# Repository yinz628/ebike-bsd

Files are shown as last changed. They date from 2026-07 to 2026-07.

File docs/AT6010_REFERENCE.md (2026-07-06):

# MS60-3015 + AT6010 协议参考手册

> 基于实测验证和两份官方文档
> - AT6010 SOC HCI Protocol v1.4 (隔空科技, 29页)
> - MS60-3015S80M4 产品手册 V1.0 (觅感科技, 8页)

---

## 1. 硬件参数

| 参数 | 数值 | 备注 |
|---|---|---|
| 工作频段 | 59~64 GHz | 60GHz FMCW |
| 水平 FOV | ±40° | 居中安装可覆盖两侧 |
| 俯仰 FOV | ±30° | |
| 探测目标数 | ≤8 | BSD 帧支持 |
| **供电电压** | **3.3V 或 5V** | ✅ 实测 5V (4.7V) 正常 |
| 平均电流 | 14 mA | 极低功耗 |
| **默认波特率** | **921600** | UART 8N1 |
| 建立探测时间 | 5 秒 | 上电后需等待 |
| **探测距离** | 汽车 50m / 摩托 30m / 自行车 25m / 行人 20m | |
| 刷新率 | 100ms (10Hz) | |
| 速度检测 | 6~90 km/h | **仅靠近方向，不检测远离** |

**引脚定义 (邮票孔, 天线面朝下):**

| 引脚 | 名称 | 类型 | 连接 |
|---|---|---|---|
| ① | 3.3V/5V | PWR | ESP32 VIN 或 3V3 |
| ② | GND | GND | ESP32 GND |
| ③ | OUT | GPIO | 悬空(可选IO输出) |
| ④ | RX | UART | ESP32 **GPIO17**(TX2) |
| ⑤ | TX | UART | ESP32 **GPIO16**(RX2) |

---

## 2. AT6010 协议帧格式

### 2.1 主动上报帧 (雷达→主机)

```
HEAD(0x5A) + LEN(1B) + PAYLOAD(LEN bytes) + CHECK(1B)
```

- **CHECK** = sum(HEAD + LEN + PAYLOAD) & 0xFF (1 字节)
- PAYLOAD 首字节为 TYPE (上报类型)

### 2.2 命令帧 (主机→雷达)

```
HEAD(0x58) + CMD_ID(1B) + LEN(1B) + PARAMS(LEN bytes) + CHECK(1B)
```

- **CMD_ID** = 命令码 (如 0x10=查询版本, 0x09=BSD设置)
- **CHECK** = sum(HEAD + CMD + LEN + PARAMS) & 0xFF (1 字节, 实测验证)

> ⚠️ 原文档描述 CHECK 为 2 字节小端，但**实测 MS60-3015 用 1 字节 CHECK**。

### 2.3 应答帧 (雷达→主机)

```
HEAD(0x59) + CMD_ECHO(1B) + LEN(1B) + DATA(LEN bytes) + CHECK(2B LE)
```

---

## 3. TYPE=7 BSD 上报格式 (§3.4.8)

### 帧结构 (实测 MS60-3015)

```
5A 09 07 [obj_num:1B] [targets: N×7B] CHECK
```

> ⚠️ 实测与文档差异: MS60-3015 BSD 模块使用简化格式——obj_num 为 1 字节（非 2 字节 LE），每目标 7 字节（非 4 字节）。

### 目标结构体 (官方格式, 校验和已验证)

```
帧格式: 5A LEN TYPE [obj_num:2B LE][reserved:2B][target:4B×N] CHECK
每目标4B: range(s8,m) + angle(s8,°) + velo(s8,m/s) + objId(s8)
```

> ✅ 已通过 4 帧原始 hex 校验和验证

```c
// §3.4.8 官方格式 (MS60-3015 使用此格式):
typedef struct {
    u16 obj_num;           // 目标数量 (2B LE)
    u16 reserved;          // 保留
    struct {
        s8 range_val;      // 距离, m
        s8 angle_val;      // 角度, ° (负=左)
        s8 velo_val;       // 速度, m/s
        s8 objId;          // 目标ID
    } obj[8];              // 最多8个目标
} bsd_det_info_t;
```

### 实测验证 (2026-06-16)

| 帧 | 原始 hex | range | angle | velo | checksum |
|----|---|:----:|:-----:|:----:|:---:|
| 1 | 5A 09 07 01 00 00 00 03 F0 00 00 5E | **3m** | -16° | 0 | ✅ |
| 2 | 5A 09 07 01 00 00 00 04 F3 00 00 62 | **4m** | -13° | 0 | ✅ |
| 3 | 5A 09 07 01 00 00 00 04 F6 00 00 65 | **4m** | -10° | 0 | ✅ |
| 4 | 5A 09 07 01 00 00 00 04 EE 00 00 5D | **4m** | -18° | 0 | ✅ |

### 实测帧例

```
5A 09 07 01 00 00 00 03 F0 00 00 5E
│  │  │  │  └─────┬─────┘  │
│  │  │  │     7B目标       CHECK
│  │  │  └ obj_num=1
│  │  └ TYPE=7
│  └ cmd_group=09 (MS60-3015特有)
└ HEAD=5A (主动上报)

解析:
  obj_id=0x00  reserved=0x0000  status=0x03(moving)
  angle=0xF0=-16°(左后方)  velo=0x0000
```

---

## 4. 常用 AT6010 命令

| 命令 | 编码 | 参数 | 说明 |
|---|---|---|---|
| 查询版本 | `58 FE 00 56 01` | 无 | 返回软硬件版本 |
| 打开雷达 | `58 D1 01 01` + csum | 0x01=开 0x00=关 | 雷达感应使能 |
| 设置等级 | `58 02 01 0F` + csum | 0~15 档 | 等级越大越灵敏 |
| 系统复位 | `58 13 01 01` + csum | 0x01=复位 | 系统重启 |
| 设置波特率 | `58 19 04` + baud(LE) + csum | 4B baud | 默认 921600 |
| 保存设置 | `58 08 01 01` + csum | 0x01=保存 | 写入 Flash |
| 获取检测信息 | `58 30 00 88 00` | 轮询方式 | 返回 20B 完整 struct |

### CMD 0x30 返回的完整检测 struct (20 字节)

```c
typedef struct {
    uint8_t  is_detected;  // 检测到目标
    uint8_t  det_result;   // 0x01=靠近 0x02=远离 0x04=运动
    uint16_t range_val;    // 距离, mm (LE)
    int16_t  angle_val;    // 角度, 1°单位 (LE, signed)
    int16_t  velo_val;     // 速度, 预留
    uint8_t  reserved[6];
    uint8_t  rb_conf;      // 距离置信度 0~16
    uint8_t  angle_conf;   // 角度置信度 0~16
    uint32_t frame_idx;    // 帧号
} fmcw_det_info_t;
```

---

## 5. 雷达启动日志

```
Boot: "at6010 boot v1.9\r\nNAK\r\ncache on\r\njump to run 0x0"
字节数: ~62 bytes (含前缀杂散字节约 173 字节)
```

---

## 6. 实测验证状态

| 项目 | 状态 | 
|---|---|
| UART 921600bps GPIO16/17 | ✅ |
| 正确 CMD 格式 (2B checksum) | ✅ |
| TYPE=7 BSD 帧解析 (range+angle+velo) | ✅ |
| 5V 供电稳定性 | ✅ |
| CMD 0xD1 响应 | ✅ 成功 |
| CMD 0x02 响应 | ✅ 成功 |
| BSD 主动上报触发 | ⚠️ 需正确使能命令 |

**已知待解决：** MS60-3015 产品手册 §3.4 提到 "具体指令格式参考觅感科技提供的指令文档" —— 这个独立的指令文档包含 BSD 使能命令，我们暂未获取。

---

## 8. 工作配置序列 (已验证 2026-06-16)

以下命令序列成功激活 MS60-3015 BSD 主动上报：

```
1. 系统复位:   58 13 01 01 6D 00
   (等待 10 秒, 雷达重启 + 建立探测)

2. 感应等级=0: 58 02 01 00 5B 00    ← Level 0=最高灵敏度!
   
3. 打开感应:   58 D1 01 01 2B 01

4. 运动灵敏度: 58 35 01 01 8F 00

5. 最远距离:   58 D2 02 88 13 2F 01  ← 5000cm = 50m
```

**关键教训：** 
- CMD 0x02 level: **0=最灵敏, 15=最不灵敏** (与直觉相反)
- 正确格式: `58 [CMD] [LEN] [PARAMS] [2B CHECKSUM_LE]`
- 建立探测时间: **5 秒**

```c
// 雷达
#define RADAR_UART  2        // UART2
#define RADAR_RX    16       // GPIO16 ← 雷达 TX(⑤)
#define RADAR_TX    17       // GPIO17 ← 雷达 RX(④)
#define RADAR_BAUD  921600

// BSD 协议
#define HEAD_REPORT  0x5A    // 主动上报帧头
#define HEAD_CMD     0x58    // 命令帧头
#define HEAD_RESP    0x59    // 应答帧头
#define REPORT_TYPE_BSD  0x07  // BSD 上报 TYPE

// LED/RCW
#define LED_FL_PIN   4       // 左前
#define LED_FR_PIN   5       // 右前
#define LED_RL_PIN   18      // 左后
#define LED_RR_PIN   19      // 右后
#define INDICATOR_L  25      // 左侧碰撞警示 LED
#define INDICATOR_R  26      // 右侧碰撞警示 LED
#define BUZZER_PIN   12      // 蜂鸣器
```

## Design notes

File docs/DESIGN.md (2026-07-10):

# 电动自行车进阶转向灯系统 — 完整设计方案 (单雷达版)

**版本:** V2.7 — WiFi控制台 + C3触摸显示
**日期:** 2026-07-08 (更新: C3连接状态指示, 心跳超时1.5s判定断开) (更新: C3显示+触摸配置, WiFi远程开关, 配置刷新同步, BSD参数清理, NVS持久化验证) (更新: GPIO合并, WiFi自动关, 官方4B帧格式确认) (更新: GPIO合并, WiFi自动关, 官方4B帧格式确认) (更新: GPIO合并, WiFi自动关, 官方4B帧格式确认) (更新: GPIO合并, WiFi自动关, 官方4B帧格式确认) (更新: GPIO合并, WiFi自动关, 官方4B帧格式确认) (更新: GPIO合并, WiFi自动关, 官方4B帧格式确认) (更新: GPIO合并, WiFi自动关, 官方4B帧格式确认) (更新: GPIO合并, WiFi自动关, 官方4B帧格式确认) (更新: GPIO合并, WiFi自动关, 官方4B帧格式确认) (更新: GPIO合并, WiFi自动关, 官方4B帧格式确认) (更新: GPIO合并, WiFi自动关, 官方4B帧格式确认) (更新: GPIO合并, WiFi自动关, 官方4B帧格式确认) (更新: GPIO合并, WiFi自动关, 官方4B帧格式确认) (更新: GPIO合并, WiFi自动关, 官方4B帧格式确认) (更新: GPIO合并, WiFi自动关, 官方4B帧格式确认) (更新: GPIO合并, WiFi自动关, 官方4B帧格式确认) (更新: GPIO合并, WiFi自动关, 官方4B帧格式确认) (更新: GPIO合并, WiFi自动关, 官方4B帧格式确认) (更新: GPIO合并, WiFi自动关, 官方4B帧格式确认) (更新: GPIO合并, WiFi自动关, 官方4B帧格式确认) (更新: GPIO合并, WiFi自动关, 官方4B帧格式确认) (更新: GPIO合并, WiFi自动关, 官方4B帧格式确认) (更新: GPIO合并, WiFi自动关, 官方4B帧格式确认) (更新: GPIO合并, WiFi自动关, 官方4B帧格式确认) (更新: GPIO合并, WiFi自动关, 官方4B帧格式确认) (更新: GPIO合并, WiFi自动关, 官方4B帧格式确认) (更新: GPIO合并, WiFi自动关, 官方4B帧格式确认) (更新: GPIO合并, WiFi自动关, 官方4B帧格式确认) (更新: GPIO合并, WiFi自动关, 官方4B帧格式确认) (更新: GPIO合并, WiFi自动关, 官方4B帧格式确认) (更新: GPIO合并, WiFi自动关, 官方4B帧格式确认) (更新: GPIO合并, WiFi自动关, 官方4B帧格式确认) (更新: GPIO合并, WiFi自动关, 官方4B帧格式确认) (更新: GPIO合并, WiFi自动关, 官方4B帧格式确认) (更新: GPIO合并, WiFi自动关, 官方4B帧格式确认) (更新: GPIO合并, WiFi自动关, 官方4B帧格式确认) (更新: GPIO合并, WiFi自动关, 官方4B帧格式确认) (更新: GPIO合并, WiFi自动关, 官方4B帧格式确认) (更新: GPIO合并, WiFi自动关, 官方4B帧格式确认) (更新: GPIO合并, WiFi自动关, 官方4B帧格式确认) (更新: GPIO合并, WiFi自动关, 官方4B帧格式确认) (更新: GPIO合并, WiFi自动关, 官方4B帧格式确认) (更新: GPIO合并, WiFi自动关, 官方4B帧格式确认) (更新: GPIO合并, WiFi自动关, 官方4B帧格式确认) (更新: GPIO合并, WiFi自动关, 官方4B帧格式确认) (更新: GPIO合并, WiFi自动关, 官方4B帧格式确认) (更新: GPIO合并, WiFi自动关, 官方4B帧格式确认) (更新: GPIO合并, WiFi自动关, 官方4B帧格式确认) (更新: GPIO合并, WiFi自动关, 官方4B帧格式确认) (更新: GPIO合并, WiFi自动关, 官方4B帧格式确认) (更新: GPIO合并, WiFi自动关, 官方4B帧格式确认) (更新: GPIO合并, WiFi自动关, 官方4B帧格式确认) (更新: GPIO合并, WiFi自动关, 官方4B帧格式确认) (更新: GPIO合并, WiFi自动关, 官方4B帧格式确认) (更新: GPIO合并, WiFi自动关, 官方4B帧格式确认) (更新: GPIO合并, WiFi自动关, 官方4B帧格式确认) (更新: GPIO合并, WiFi自动关, 官方4B帧格式确认) (更新: GPIO合并, WiFi自动关, 官方4B帧格式确认) (更新: GPIO合并, WiFi自动关, 官方4B帧格式确认) (更新: GPIO合并, WiFi自动关, 官方4B帧格式确认)
**状态:** ✅ V2.7 | 21参数(NVS持久化) | C3触摸屏配置 | WiFi远程开关 | 雷达可视化 | 后方监测两级报警 | 目标自动消失 | 正确AT6010命令 | KiCad原理图+PCB
**参考:** [AT6010_REFERENCE.md](AT6010_REFERENCE.md) — 协议帧格式、命令表、BSD帧结构
**作者:** Hermes Agent (for 许国方)

---

## 目录

1. [系统概述](#1-系统概述)
2. [硬件选型与BOM](#2-硬件选型与bom)
3. [电路原理图](#3-电路原理图)
4. [固件设计](#4-固件设计)
5. [安装指南](#5-安装指南)
6. [分步焊接调试指南](#6-分步焊接调试指南)
7. [调试方法（完整系统）](#7-调试方法完整系统)
8. [platformio.ini 参考配置](#8-platformioini-参考配置)
9. [安全免责声明](#9-安全免责声明)
10. [参考链接](#10-参考链接)

---

## 1. 系统概述

### 1.1 方案对比

| 版本 | 雷达数量 | 总成本 | 接线复杂度 | 说明 |
|:----:|:---:|:---:|:---:|---|
| V1.0 | **2个** | ¥344 | 中等 | 左右各一个雷达，各占一个UART |
| **V2.1** | **1个** | **¥261** | **简单** | **居中安装，angle字段判左右** |

**为什么1个雷达就够了？**

MS60-3015 的 BSD 协议为每个检测到的目标输出 **角度值（angle）**，范围 -64°~+63°，左负右正。雷达水平 FOV 为 **±40°**，覆盖 80° 范围：

```
雷达居中安装, 天线正对正后方：

    左后方          正后方          右后方
  ─40° ─── ─15° ─── 0° ─── +15° ─── +40°
         │                      │
   盲区范围                 盲区范围
   (左车道)                (右车道)
```

- angle < 0 → 目标在左后方
- angle > 0 → 目标在右后方
- 按 angle 范围即可区分左右盲区，无需两个雷达

### 1.1.1 AT6010 协议实测验证 (2026-06-16)

MS60-3015 基于**隔空 AT6010 60GHz SOC**，协议遵循 AT6010 HCI Protocol v1.4。

**主动上报帧格式（雷达→主机）：**
```
HEAD(0x5A) + LEN(1B) + PAYLOAD(LEN bytes) + CHECK(1B)
```
- CHECK = sum(HEAD + LEN + PAYLOAD) & 0xFF（1 字节校验和）
- PAYLOAD 首字节为 TYPE（上报类型）

**实测 BSD 帧（TYPE=0x07，厂商自定义）：**
```
5A 09 07 01 00 00 00 03 2D 00 00 9B
│  │  │  │  └─────┬─────┘ └┬┘ └┬┘  │
│  │  │  │    reserved   status angle reserved
│  │  │  └─ obj_count=1           (0x03=运动)
│  │  └─ TYPE=0x07 (BSD vendor)   (0x04=微动)
│  └─ LEN=9 bytes
└─ HEAD=0x5A
```
- 角度(angle): `int8_t`, 符号角度，正=右，负=左
- 状态(status): `0x03`=运动目标, `0x04`=微动目标
- **仅检测到目标时上报，无目标则静默**

**命令帧格式（主机→雷达）：**
```
HEAD(0x58) + CMD_GROUP(1B) + CMD(1B) + LEN(1B) + PARAMS(LEN) + CHECK(1B)
```
- 配置命令组 CMD_GROUP = 0x01
- 命令示例：ENABLE_BSD(0x05), SET_DET_RANGE(0x02), SET_SENSITIVITY(0x03)

**关键参数：**
- 默认波特率：**921600**（不是 115200）
- 供电：**支持 5V**（文档标注已支持）
- 启动日志：`at6010 boot v1.9\r\nNAK\r\ncache on\r\njump to run 0x0`
- ESP32 引脚：GPIO16(RX2) ← 雷达TX，GPIO17(TX2) → 雷达RX

### 1.2 功能列表

| 功能 | 说明 | 优先级 |
|---|---|:---:|
| **转向前后灯** | 左右两路（同侧前后并联），1.5Hz；三档开关左/右/关直控 | P0 |
| **后方监测 (BSD+RCW合并)** | 60GHz 雷达探测后方车辆，按速度两级报警：低速→1Hz慢闪+蜂鸣单声，高速→4Hz快闪+4Hz蜂鸣 | P0 |
| **转向辅助** | 打转向灯时自动判断该方向是否有接近车辆，危险时指示灯常亮+蜂鸣长鸣 | P0 |
| **双闪警示** | 已移除 — 无硬件开关 | — |

### 1.3 系统框图

```
                      ┌──────────────────────────────────┐
                      │            48V 电瓶               │
                      └──────────┬───────────────────────┘
                                 │
                           ┌─────▼──────┐
                           │ DC-DC 48V→ │
                           │   12V      │  XL7015
                           └─────┬──────┘
                                 │ 12V
                    ┌────────────┼────────────┐
                    │            │            │
              ┌─────▼─────┐ ┌───▼───┐  ┌────▼────┐
              │ AMS1117   │ │转向灯 │  │转向灯   │
              │ 12V→3.3V  │ │前左   │  │前右     │
              └─────┬─────┘ └───▲───┘  └────▲────┘
                    │ 3.3V      │            │
              ┌─────▼─────┐  MOSFET     MOSFET
              │   ESP32   │  Q1(IRLZ44N) Q2(IRLZ44N)
              │  主控     │
              └─────┬─────┘                  │
                    │ UART2              ┌───▼────┐
              ┌─────┼──────┐       ┌────▼──┐ ┌───▼───┐
         ┌────▼┐ ┌──▼───┐ ┌──▼──┐ │转向灯│ │转向灯 │
         │MS60 │ │蜂鸣器│ │转向 │ │后左  │ │后右   │
         │雷达 │ │PWM   │ │开关 │ │     │ │       │
         │UART │ │      │ │     │ │Q3   │ │Q4     │
         └─────┘ └──────┘ └──┬──┘ └──────┘ └───────┘
                              │
              ┌───────────────┼────────────────┐
              │               │                │
         ┌────▼────┐    ┌─────▼────┐    ┌─────▼────┐
         │左指示灯 │    │双闪按钮  │    │右指示灯  │
         │LED+220Ω│    │ (HAZARD) │    │LED+220Ω  │
         │ GPIO25  │    │ GPIO27   │    │ GPIO26   │
         └─────────┘    └──────────┘    └──────────┘
```

### 1.4 三大输出设备 — 转向灯 / LED指示灯 / 蜂鸣器

系统包含三类独立的输出设备，各司其职：

| 设备 | 硬件 | 用途 | 感知对象 |
|---|---|---|---|
| **转向灯** | 12V LED（前后四灯），MOSFET 驱动 | 向**其他交通参与者**发出转向/双闪/警示信号 | 外部车辆/行人 |
| **LED指示灯** | 5mm 红色 LED ×2，GPIO 直驱 | 向**骑行者**发出后方危险方向提示 | 骑行者本人 |
| **蜂鸣器** | 压电蜂鸣器，PWM 驱动 | 向**骑行者**发出听觉警报 | 骑行者本人 |

```
               ┌──────────┐
               │  ESP32   │
               └────┬─────┘
                    │
      ┌─────────────┼─────────────┐
      │             │             │
  ┌───▼───┐   ┌────▼────┐   ┌───▼───┐
  │MOSFET │   │  GPIO   │   │ GPIO  │
  │×4 驱动│   │ 直驱LED │   │ 蜂鸣器│
  └───┬───┘   └────┬────┘   └───┬───┘
      │             │             │
  12V转向灯    指示灯(L/R)   5V蜂鸣器
  前左/前右    GPIO25/26     GPIO12
  后左/后右    5mm红色       压电式
```

#### 1.4.1 转向灯（Turn Signals）

转向灯是系统的**主要外部信号**，安装于车辆前后四角，12V 摩托车 LED 成品，经 MOSFET 由 ESP32 控制。

| 场景 | 转向灯行为 | 频率 | 目的 |
|---|---|:---:|---|
| **左转向** | 左前 + 左后同步闪烁 | 1.5Hz | 告知后方你即将左转 |
| **右转向** | 右前 + 右后同步闪烁 | 1.5Hz | 告知后方你即将右转 |
| **双闪 (HAZARD)** | 四灯同步闪烁 | 3Hz (快闪) | 紧急停靠 / 恶劣天气 |

**关键设计**：转向辅助检测到危险时**不改变转向灯频率**。转向灯始终保持标准 1.5Hz，让其他道路使用者正确理解你的转向意图。危险提醒通过指示灯和蜂鸣器单独传达给骑行者。

#### 1.4.2 LED 指示灯（Indicator LEDs）

指示灯是**骑行者专属视觉提醒**，安装在手把仪表区域，5mm 红色高亮 LED 串 220Ω 电阻，ESP32 GPIO 直驱（无需 MOSFET）。自然对应左右方向，骑行时余光可见。

| 场景 | 左指示灯 (GPIO25) | 右指示灯 (GPIO26) | 目的 |
|---|:---:|:---:|---|
| **无目标** | 灭 | 灭 | 安静巡航 |
| **后方低速目标** (2-3 m/s) | 🔴 1Hz 慢闪 | — | 提醒侧方有车 |
| **后方高速目标** (≥3 m/s) | 🔴 4Hz 快闪 | — | 后方快速接近 |
| **转向辅助** | 🔴 常亮 | — | 警告：转向方向有车 |
| **转向辅助+高速目标** | 🔴 4Hz 快闪 | — | 高速目标覆盖转向（更高优先） |

> V2.6: BSD+RCW合并为统一后方监测，按速度两级报警。低速→IND_MODE_BSD(1Hz)，高速→IND_MODE_RCW(4Hz)。

**优先级规则**（仅适用后方监测 vs 转向辅助）：
- 后方监测检测到快速目标时，指示灯由 RCW 模式控制（4Hz 快闪）。
- 转向辅助检测到危险时，指示灯常亮（被 RCW 快闪覆盖时降级）。

#### 1.4.3 蜂鸣器（Buzzer）

蜂鸣器是**听觉警报**，12V 高分贝有源蜂鸣器，通过 **IRLZ44N MOSFET (Q1)** 驱动。GPIO12 经 1kΩ 电阻接栅极，漏极接蜂鸣器负极，蜂鸣器正极接 12V。HIGH=响，LOW=灭。

| 优先级 | buzzer_mode | 触发条件 | 蜂鸣模式 |
|:---:|:---:|---|---|
| **最高 (2)** | 2 | RCW 后碰撞预警 | 4Hz 短促鸣响 |
| **高 (3)** | 3 | 转向辅助检测到同侧危险 | **持续长鸣** |
| **中 (1)** | 1 | BSD 盲区首次检测到目标 | 单次 100ms 短鸣，冷却 5s |
| **最低 (0)** | 0 | 无警报条件 | 静音 |

**优先级规则**：
- `buzzer_mode == 2`（高速4Hz）/ `3`（转向长鸣）覆盖模式 1（低速单鸣）。
- 低速蜂鸣有 5 秒冷却（由 `sys.bsd_beep_cooldown` 控制）。

#### 1.4.4 场景交互矩阵

| # | 场景 | 转向灯 | 左指示灯 | 右指示灯 | 蜂鸣器 |
|---|---|:---:|:---:|:---:|:---:|
| 1 | 无操作，后方无车 | 灭 | 灭 | 灭 | 静音 |
| 2 | 无操作，后方低速目标 | 灭 | 🔴 1Hz慢闪 | 灭 | 🔔 单鸣 |
| 3 | 无操作，后方高速目标 | 灭 | 🔴 4Hz快闪 | 灭 | 🔊 4Hz |
| 4 | 打左转向，左后安全 | ↙ 1.5Hz | 灭 | 灭 | 静音 |
| 5 | 打左转向，左后有车 | ↙ 1.5Hz | 🔴 常亮 | 灭 | 🔊 长鸣 |
| 6 | 打左转 + 后方高速目标 | ↙ 1.5Hz | 🔴 4Hz快闪 | 灭 | 🔊 4Hz |

### 1.5 工作模式流程

```
开机初始化
    │
    ├── 配置雷达 (UART2, 921600bps)
    │     ├── 设置探测距离 30m
    │     ├── 设置灵敏度
    │     └── 启用 BSD 主动上报 (TYPE=7, 4B目标格式)
    │
    ├── 主循环 (每 50ms)
    │     │
    │     ├── 读取转向开关状态 (自锁式)
    │     │     ├── 左位(LOW) → 左转向灯闪烁 (1.5Hz)
    │     │     ├── 右位(LOW) → 右转向灯闪烁 (1.5Hz)
    │     │     └── 中间(HIGH) → 关闭转向灯
    │     │
    │     ├── 解析雷达UART数据 (BSD主动上报, TYPE=7)
    │     │     ├── obj_num(2B LE) + reserved(2B)
    │     │     ├── 每个目标4B: range(s8,m) + angle(s8,°) + velo(s8,m/s) + objId(s8)
    │     │     └── 按 angle 分类左/右 (REAR_ANGLE_IS_LEFT/RIGHT)
    │     │
    │     ├── 后方监测逻辑 (BSD+RCW合并, updateRCW)
    │     │     ├── 低速目标 (≥low_speed, <speed_threshold) → IND_MODE_BSD (1Hz慢闪) + 蜂鸣单声(5s冷却)
    │     │     ├── 高速目标 (≥speed_threshold) → IND_MODE_RCW (4Hz快闪) + 蜂鸣4Hz
    │     │     └── 超时解除 (hold_time)
    │     │
    │     ├── 转向辅助逻辑 (打转向灯时, 仅新帧触发)
    │     │     ├── 帧新鲜度检查 (避免旧帧重复触发 — V2.5修复)
    │     │     ├── 同侧有接近目标 (速度>7.2km/h, 距离<30m)
    │     │     │     ├── 设置同侧灯 IND_MODE_TURN (常亮)
    │     │     │     ├── 蜂鸣器 持续长鸣 (buzzer_mode=3)
    │     │     │     └── 转向灯保持正常 1.5Hz (不改变频率)
    │     │     └── 同侧无危险 → 模式归零, 蜂鸣停
    │     │
    │     ├── 指示灯集中状态机 (updateIndicatorLEDs)
    │     │     ├── 读取 ind_left_mode / ind_right_mode
    │     │     ├── IND_MODE_OFF → 灭
    │     │     ├── IND_MODE_BSD → 1Hz 慢闪 (500ms半周期)
    │     │     ├── IND_MODE_RCW → 4Hz 快闪 (125ms半周期, 与蜂鸣同步)
    │     │     └── IND_MODE_TURN → 常亮
    │
    └── 循环
```

---

### 1.4 验证状态 (2026-06-16 实测)

| 功能 | 硬件 | 状态 |
|---|---|:--:|
| BSD 盲区检测 | 雷达→ESP32 | ✅ |
| RCW 后碰撞预警 | 雷达→ESP32 | ✅ |
| 左/右 RCW LED | GPIO25/26 直驱 5mm 红色 LED | ✅ |
| 蜂鸣器 | GPIO12 直驱 3针有源模块 (VCC/GND/I/O) | ✅ |
| 网页调试控制台 | `http://localhost:8080` 实时数据+命令发送 | ✅ |
| 转向灯 (LED) | GPIO4/5/18/19 + MOSFET | 待测 |
| 转向开关 | GPIO13/14/15 | 待测 |

**LED 行为：** 帧时间戳去重 → 新目标触发 → 3 秒无新帧自动灭
**RCW 行为：** 速度>1m/s + 距离<20m → LED+蜂鸣 → 危险消失延续 3 秒关闭
**蜂鸣器：** 有源 3 针模块 (VCC→3V3, GND→GND, I/O→GPIO12)，高电平触发

### 1.5 网页调试控制台

```bash
python3 tools/web_console.py   # 启动后访问 http://localhost:8080
```

- 📊 主面板：实时 BSD 目标数据 (距离/角度/速度)、LED/蜂鸣器状态
- 📝 原始数据：RAW hex 帧
- 📋 事件日志：盲区/RCW/配置事件
- ⚙ 设置面板：盲区角度、LED 超时等参数
- 📡 命令面板：15 条 AT6010 命令一键发送到雷达

## 2. 硬件选型与BOM

### 2.1 物料清单（详细淘宝版）

| 序号 | 名称 | 规格要点 | 数量 | 单价(¥) | 小计 | 淘宝搜索关键词 |
|:----:|---|---|:----:|:---:|:----:|---|
| 1 | **ESP32 主控** | ESP32-32D, 38pin, MicroUSB, 板载天线, 丝印直标GPIO号(非D编号) | 1 | 20~30 | 25 | `ESP32-32D 38pin 开发板` |
| 2 | **60GHz 雷达** | 觅感 MS60-3015S80M4, BSD版, 5pin邮票孔, 3.3V | **1** | 79~89 | **79** | `MS60-3015 觅感 60G雷达` |
| 3 | **转向灯×2 前** | 12V 琥珀色, 摩托车成品, 带金属支架+螺丝, 防水, 线头已引出 | 1对 | 15~30/对 | 20 | `摩托车转向灯 LED 12V 琥珀` |
| 4 | **转向灯×2 后** | 同上, 尺寸可以稍短 (≤8cm) | 1对 | 15~25/对 | 20 | `摩托车转向灯 LED 后转向 短款` |
| 5 | **MOSFET 驱动** | IRLZ44N, TO-220, N沟道, Vgs(th)=1V | 4 | 1.5~3 | 8 | `IRLZ44N 逻辑电平` |
| 6 | **转向开关** | 摩托车三档(左-关-右), 自锁式(推到位停留), 手把安装, 孔径22mm或夹具型 | 1 | 12~22 | 18 | `电动车转向灯开关 三档 自锁` |
| 7 | **蜂鸣器** | 有源电磁/压电 5V, φ12mm, 内置驱动, 85dB+ | 1 | 2~4 | 3 | `有源蜂鸣器 5V 12mm` |
| 8 | **DC-DC 降压** | XL7015 模块, 输入5~80V, 输出12V 5A, 带散热 | 1 | 10~15 | 13 | `XL7015 降压模块 80V 12V` |
| 9 | **3.3V 稳压** | AMS1117-3.3V 模块, 输入12V, 输出3.3V 1A | 1 | 2~5 | 4 | `AMS1117 3.3V 模块` |
| 10 | **万能板** | 玻纤单面 7×9cm, 2.54mm 孔距 | 1 | 3~5 | 4 | `万能板 7x9 玻纤` |
| 11 | **OLED 屏 (可选)** | SSD1306, 0.96寸, 128×64, I2C, 白色 | 1 | 8~12 | 10 | `SSD1306 0.96寸 I2C` |
| 12 | **防水盒** | IP65 ABS, 内尺寸 ≥120×80×50mm, 带密封圈 | 1 | 9~14 | 13 | `防水接线盒 IP65 120 80 50` |
| 13 | **硅胶线** | RV 0.5mm², 耐高温200°C, 5色×1m | 5m | 2/m | 10 | `硅胶线 0.5平方 多色` |
| 14 | **杜邦线** | 母-母 20cm, 2.54mm, 40根装 | 1套 | 5~8 | 6 | `杜邦线 母对母 2.54` |
| 15 | **电阻包** | 1/4W 金属膜: 1kΩ×10 + 10kΩ×10 | 1套 | 3~5 | 4 | `电阻包 1k 10k 1/4W` |
| 16 | **保险丝** | 汽车插片式, 5A 慢熔 + 防水座, 带30cm线 | 1 | 3~5 | 4 | `汽车保险丝座 防水 5A` |
| 17 | **热缩管** | φ2/φ4/φ6 各30cm, 带胶防水 | 1套 | 5~8 | 6 | `热缩管 带胶 套装` |
| 18 | **XT30 插头** | 公母对, 含热缩管, 硅胶线预焊 | 2对 | 3~5/对 | 8 | `XT30 插头 带线` |
| 19 | **排针排母** | 2.54mm, 单排, 1×40pin 直插 | 2条 | 2 | 4 | `2.54 排针 单排 40pin` |
| 20 | **指示灯LED** | 5mm 红色高亮, 20mA; + 220Ω 1/4W电阻 ×2 | 2套 | 1~2 | 2 | `5mm LED 红色 高亮` |
| | | **合计** | | | **~¥261** | |

> **注**：
> - 价格区间取淘宝中等价位实价，非拼多多极限低价
> - 不含工具：电烙铁(60W+)、焊锡丝(0.8mm 63/37)、万用表、热风枪、斜口钳等
> - MS60-3015 务必从**觅感科技官方淘宝店**购买，确认是 BSD 版本 (支持 TYPE=7 主动上报)，别买到非 BSD 固件版本
> - 转向灯买**2对 = 4个**（前2 + 后2）。推荐选 **子弹头/箭头造型**、**灯罩长度6~10cm** 的款式，太大不好装但亮度高

### 2.2 转向灯成品推荐

本方案使用 **淘宝成品 12V 摩托车 LED 转向灯**，无需自己 DIY LED 灯条：

| 推荐选择 | 说明 | 参考价/对 |
|---|---|:---:|
| **子弹头款** | 经典造型，直径2~3cm，长6~8cm，金属外壳+琥珀色灯罩，防水 | ¥15~25 |
| **短款圆灯** | 直径4~5cm，长3~4cm，适合后灯，省空间 | ¥15~20 |
| **日行灯+转向二合一** | 白色日行灯常亮 + 琥珀色转向切换，需3线接法 | ¥30~40 |
| **流水转向灯** | 动态跑马灯效果，好看但功耗稍大(1A左右)，注意MOSFET散热 | ¥25~50 |

**选购要点：**
- ✅ 电压 **12V DC**（快接我们降压后的12V母线）
- ✅ 灯罩颜色 **琥珀/橙色**（法规要求转向灯为黄色）
- ✅ 带金属安装支架 + 固定螺丝
- ✅ 2线制（正极 + 负极），不要买3线制（多了行车灯线，接线更复杂）
- ✅ 标注防水等级 IP65+
- ✅ 单只功率 **3~10W**（12V 下电流 0.25~0.8A，IRLZ44N 轻松应对）
- ❌ 不要买带闪频器的"即插即闪"款（闪频器输出脉冲会干扰我们的 PWM 控制）

**接线方式（不变）：**
```
+12V 母线 ─────→ 转向灯正极（红线）
转向灯负极 ────→ IRLZ44N 漏极 (D)
IRLZ44N 源极 ──→ GND
ESP32 GPIO ──1kΩ──→ IRLZ44N 栅极 (G)
IRLZ44N 栅极 ──10kΩ──→ GND (下拉, 防止未初始化时误亮)
```

### 2.3 转向开关选购

推荐**摩托车左手把三档开关**：

|| 类型 | 安装方式 | 手感 | 参考价 ||
||---|---|---|:---:||
|| **手把管夹式** | 夹在车管上(22mm管径) | 大拇指推拨 | ¥15~22 ||
|| **车把塞入式** | 直接塞入手把管末端 | 旋钮旋转 | ¥12~18 ||

结构：三档自锁式（左-关-右），推到位后**停留在该位置**，不回弹。ESP32 直读 GPIO 电平判断当前档位（左=LOW→左闪，右=LOW→右闪，中间=HIGH→关闭）。推荐**管夹式**，因为电瓶车手把管径一般 22mm 刚好适配。

**双闪按钮（HAZARD）：** ⚠️ V2.6已移除, 无双闪功能。以下为历史描述——额外安装一个独立的自锁按钮，接 GPIO27（内部上拉，按下=LOW）。短按进入双闪模式（四灯同时闪烁），再按退出。用于紧急停靠、恶劣天气等场景。按钮可安装在左手把开关旁边或仪表盘上。

### 2.4 关键器件详细说明

**MS60-3015 雷达（核心器件）：**
- 60GHz FMCW 毫米波，专为户外低速车辆 BSD 设计
- 探测距离：汽车50m / 摩托车30m / 自行车25m / 行人20m
- 直接 UART 输出 **角度(°) + 状态**，每目标 **7 字节**（含保留字段）
- 水平 FOV **±40°** — 单个居中即可覆盖两侧盲区
- 主动上报模式，100ms刷新 (10Hz)，无需轮询
- 3.3V / 14mA 超低功耗，尺寸 29.8×15mm
- 引脚：①3.3V ②GND ③OUT(悬空) ④RX ⑤TX
- 默认波特率 **921600**，固件使用 921600

**IRLZ44N MOSFET：**
- 逻辑电平 N-MOS，Vgs(th) ≈1V，ESP32 3.3V GPIO **完全可驱动**
- 导通电阻 Rds(on) ≈22mΩ @Vgs=5V（5V时更好，但3.3V也能用）
- 连续漏极电流 47A，远超转向灯 (<1A)
- TO-220 封装，不发热（0.8A × 22mΩ = 14mW 功耗）
- 每个 MOSFET 需配：1kΩ 栅极限流电阻 + 10kΩ 栅-源下拉电阻

**XL7015 降压模块：**
- 输入 5~80V DC（48V电瓶充满55V也在安全范围内）
- 输出 12V 5A，效率 ~85%
- 模块自带散热片、电感、滤波电容
- 输出 12V 母线同时给：LED 转向灯×4 (≤40W) + AMS1117 → ESP32/雷达

**AMS1117-3.3V 稳压模块：**
- 输入 12V，输出 3.3V 1A
- 给 ESP32 + MS60-3015 雷达供电
- **重要**：雷达的 3.3V 必须从这个 AMS1117 取电，不要用 ESP32 板载 3.3V（板载电流不够 50mA+，且会引入噪声干扰雷达）

---

## 3. 电路原理图

### 3.1 电源电路

```
48V输入 (电瓶正极)
    │
    ├── 保险丝 5A (慢熔)
    │       │
    │   ┌───▼──────────────────┐
    │   │   XL7015 DC-DC       │
    │   │   48V → 12V 3A       │
    │   └───┬──────────────────┘
    │       │ +12V
    │       │
    │   ┌───▼──────────────────┐
    │   │   AMS1117-3.3V       │
    │   │   12V → 3.3V 1A      │
    │   └───┬──────────────────┘
    │       │ +3.3V (给ESP32 + 雷达供电)
    │       │
    └───────┴── GND (共地)

注: 48V 正极必须先过保险丝再接入 XL7015
    ESP32 Vin 可接 12V (板载有 1117-3.3V 稳压), 也可接 AMS1117 的 3.3V 输出
    MS60-3015 雷达可直接从 ESP32 5V 引脚取电（文档标注支持 5V，实测 4.7V 正常工作），或从 AMS1117 取 3.3V
```

### 3.2 ESP32 引脚分配

| GPIO | 功能 | 连接 | 方向 | 说明 |
|:----:|---|---|:----:|---|
| GPIO16 | UART2 RX | 雷达 TX | ←输入 | MS60-3015 数据接收 |
| GPIO17 | UART2 TX | 雷达 RX | 输出→ | 配置命令发送 |
| GPIO4 | PWM CH0 | 左转向MOSFET栅极 (左前+左后并联) | 输出→ | V2.6起同侧并联 |
| GPIO23 | PWM CH1 | 右转向MOSFET栅极 (右前+右后并联) | 输出→ | V2.6起同侧并联 |
| GPIO12 | 蜂鸣器 | BUZZER MOSFET栅极 | 输出→ | 12V有源蜂鸣器 |
| GPIO13 | 左转向开关 | SW_LEFT → GND (内部上拉) | 输入 | 三档自锁开关 |
| GPIO14 | 右转向开关 | SW_RIGHT → GND (内部上拉) | 输入 | 三档自锁开关 |
| GPIO18 | UART1 TX | C3显示面板RX (GPIO19) | 输出→ | 心跳+目标数据 |
| GPIO19 | UART1 RX | C3显示面板TX (GPIO18) | ←输入 | C3配置命令接收 |
| **GPIO25** | **左指示灯** | **5mm红色LED + 220Ω → GND** | **输出→** | 骑行者左后方危险指示 |
| **GPIO26** | **右指示灯** | **5mm红色LED + 220Ω → GND** | **输出→** | 骑行者右后方危险指示 |
| GND | 电源地 | 所有GND共地 | — | |

> **板子丝印对照**：本板 GPIO 号直接印在排针旁边（如 "16" = GPIO16，不是 D16）。左侧排针：3V3/EN/UP/VN/34/35/32/33/25/26/27/14/12/GND/13；右侧排针：GND/22/23/TX/RX/21/GND/19/18/5/17/16/4/0/2/15。

> **⚠ 禁止使用的引脚**：
> - **TX/RX** — UART0 系统串口，留给电脑调试
> - **CLK/CMD** — SPI Flash 引脚，碰了芯片变砖
> - **D0(0)/D2(2)** — Boot 引脚，不要占用
> - **34/35/UP(36)/VN(39)** — 仅输入，不能驱动 LED/MOSFET
> - **EN** — 复位脚

### 3.3 转向灯驱动电路 (每路灯完全相同, ×4)

```
         +12V
           │
         ┌─┴──┐
         │ LED│  12V 摩托车转向灯成品
         │转向│  ≤800mA
         └─┬──┘
           │
           │  D (漏极)
         ┌─┴──┐
    3.3V │    │
    ──┬──┤ G  │ IRLZ44N (N-MOS 逻辑电平)
      │ │    │
      │ └─┬──┘
      │   │ S (源极)
      │   │
      │  GND
      │
     1kΩ ███  (栅极限流, 防振荡)
      │
      └── ESP32 GPIO

    额外: 栅-源间并联 10kΩ 下拉电阻 (ESP32 未初始化时保持关闭)
    转向灯反向并联 1N4007 二极管 (吸收关断尖峰)
```

### 3.4 雷达模块连接

```
    ┌──────────────────────────────────┐
    │         MS60-3015S80M4           │
    │                                  │
    │ 1: 3.3V ────── 3.3V / 5V 均可   │
    │ 2: GND  ────── ESP32 GND        │
    │ 3: OUT  ────── (悬空/保留)       │
    │ 4: RX   ────── ESP32 GPIO17(TX2)│
    │ 5: TX   ────── ESP32 GPIO16(RX2)│
    └──────────────────────────────────┘

  注: 雷达支持 3.3V 和 5V 供电 (产品手册客制化选项确认)
      实测 5V 供电时引脚电压约 4.7V, 工作正常
      平均功耗 14mA, ESP32 板载 3.3V 足够
      默认波特率 921600 (已确认)
```

### 3.4.1 协议验证 (2026-06-16 调试确认)

**帧格式 (实测):**

| 字段 | 代码常量 | 预期值 | 实际值 | 说明 |
|---|---|---|---|---|
| 主动上报帧头 | BSD_FRAME_HEADER | 0x58 | **0x5A** | AT6010 主动上报用 0x5A |
| 配置命令帧头 | CONFIG_FRAME_HEADER | 0x58 | **0x58** | 主机→雷达命令用 0x58 |
| 命令组 | BSD_CMD_GROUP | 0x07 | **0x09** | MS60-3015 BSD模块实际值 |
| 数据类型 | BSD_CMD_TYPE_DATA | 0x07 | **0x07** | TYPE=7 完整检测信息 |
| 校验和算法 | — | 累加和+取低8位 | ✅ 验证通过 |

**BSD 目标帧结构 (每目标 7 字节):**

```
字节: 0     1-2      3        4         5-6
内容: obj_id reserved status  angle(有符号) velocity
```

**实测帧示例 (挥手时):**
```
5A 09 07 01 00 00 00 03 F0 00 00 5E  → 1个目标, 角度=-16°(左后方)
5A 09 07 01 00 00 00 04 F3 00 00 62  → 1个目标, 角度=-13°(左后方)
```

**雷达启动日志 (921600bps):**
```
at6010 boot v1.9\r\nNAK\r\ncache on\r\njump to run 0x0
```
约173字节, 启动后如果无目标则静默 (文档确认:"仅检测到目标才输出")

### 3.5 完整接线表

| ESP32 引脚 | 连接端 | 备注 |
|---|---|---|
| 3.3V | AMS1117-3.3V 输出 | ESP32 和雷达共同供电 |
| GND | 所有 GND 共地 | 雷达、MOSFET 源极、蜂鸣器、开关、OLED |
| GPIO16 (RX2) | 雷达 TX | UART 921600bps |
| GPIO17 (TX2) | 雷达 RX | |
| GPIO4 → 1kΩ → | IRLZ44N Q1 栅极 | 左前 LED (FL) |
| GPIO23 → 1kΩ → | IRLZ44N Q2 栅极 | 右前 LED (FR) |
| GPIO13 | 开关左 → GND (按下=LOW) | 内部上拉 |
| GPIO14 | 开关右 → GND | 内部上拉 |
| GPIO27 | 双闪按钮 → GND | 内部上拉 |
| GPIO12 | 蜂鸣器 I/O | 高电平触发, 3针有源模块(VCC→3V3,GND→GND,I/O→GPIO12) |
| GPIO25 | 左指示灯LED+ | 串220Ω到GND, 5mm红色 |
| GPIO26 | 右指示灯LED+ | 串220Ω到GND, 5mm红色 |
| GPIO21 (SDA) | OLED SDA | 可选, 上拉4.7kΩ |
| GPIO22 (SCL) | OLED SCL | 可选, 上拉4.7kΩ |

---

## 4. 固件设计

### 4.1 开发环境

- **Platform:** Arduino IDE / PlatformIO
- **Board:** ESP32 Dev Module
- **Core:** ESP32 Arduino Core 2.0.14+
- **Libs:** HardwareSerial (内置), Wire.h (OLED)

### 4.2 软件架构

```
firmware/
  ├── ebike_bsd.ino     主程序 (setup + loop)
  ├── bsd_protocol.h    MS60-3015 BSD 协议解析
  ├── ms60_radar.h      MS60-3015 雷达 UART 驱动
  ├── led_control.h     LED PWM 驱动 (4路)
  └── oled_display.h    OLED 显示 (可选, 编译开关)
```

### 4.2.1 看门狗

// 雷达供电: 5V (实测4.7V, 文档确认支持5V)
固件启用 ESP32 硬件看门狗（`esp_task_wdt`），超时 **5 秒**。主循环每次迭代调用 `esp_task_wdt_reset()` 喂狗。若主循环因异常卡死（如 UART 死锁），看门狗超时后自动重启 ESP32，确保系统不会长时间无响应。

### 4.2.2 蜂鸣器优先级

蜂鸣器采用状态机控制，优先级从高到低：

| 优先级 | buzzer_mode | 触发条件 | 蜂鸣模式 |
|:---:|:---:|---|---|
| 最高 | 2 | RCW 后碰撞预警 (>10.8km/h) | 4Hz 急促鸣响 |
| 高 | 3 | 转向辅助检测到同侧危险 | 持续长鸣 |
| 中 | 1 | BSD 盲区首次检测到目标 | 单次短鸣 (100ms)，冷却 5s |
| 最低 | 0 | 无警报 | 静音 |

**规则**：低优先级不会打断高优先级。BSD 只在 `buzzer_mode==0` 时设置为 1；RCW 设置为 2（覆盖 BSD）；转向辅助设置为 3（覆盖 BSD，但不覆盖 RCW）。关转向时清除 mode 2/3，关 RCW 时清除 mode 2。

### 4.3 角度分区策略

```
雷达法线方向 = 正后方 (0°)

左盲区   [-40° ~ -15°]   → bsd_l_active = true
           (左侧车道后方来车)

正后方    [-14° ~ +14°]  → 不触发盲区报警
           (同车道后方跟车, 正常)

右盲区   [+15° ~ +40°]   → bsd_r_active = true
           (右侧车道后方来车)

转向辅助范围 (比 BSD 稍宽, 为安全):
  左转辅助: [-40° ~ -5°]
  右转辅助: [+5° ~ +40°]
```

### 4.4 核心算法

```cpp
// === BSD 盲区：按 angle 分类左右 ===
void updateBSD() {
    for each target:
        if angle in [-40°, -15°] AND range < 30m:
            bsd_l_active = true
        if angle in [+15°, +40°] AND range < 30m:
            bsd_r_active = true
        // 正后方 [-14°, +14°] 不触发
    if !rcw_l_active: INDICATOR_L = bsd_l_active ? ON : OFF
    if !rcw_r_active: INDICATOR_R = bsd_r_active ? ON : OFF
    if bsd_*_active && !warned && buzzer_mode == 0:
        buzzer_mode = 1   // 单次短鸣, 5s冷却
}

// === RCW 后碰撞预警：高速接近 ===
void updateRCW() {
    for each target:
        if abs(velocity) < 3m/s OR range > 25m: skip
        if angle in [-40°, -5°]:  leftFast = true
        if angle in [+5°, +40°]:  rightFast = true
    if leftFast:  INDICATOR_L = ON; buzzer_mode = 2  // 4Hz
    if rightFast: INDICATOR_R = ON; buzzer_mode = 2
}

// === 转向辅助：打灯时判断同侧危险 (仅新帧触发) ===
function turn_assist(turn_dir):
    if frame_timestamp == last_ts: return  // V2.5: 防旧帧重复触发
    for each target:
        if velocity < 2m/s OR range > 30m: skip
        if turn_dir == LEFT  AND angle in [-40°, -5°]: danger = true
        if turn_dir == RIGHT AND angle in [+5°, +40°]: danger = true
    if danger:
        set_indicator(on, side)  // 同侧指示灯常亮
        buzzer_mode = 3          // V2.5: 持续长鸣
    else:
        clear_indicator(side)    // 保留 RCW 的判断
        clear_buzzer_if_not_rcw()
```

### 4.5 主循环时序

```
loop() 每 50ms 执行一次:

  [0ms]   读取转向开关 (自锁式, 直读电平)
  [0ms]   雷达 UART 数据读取 + 帧同步解析
  [2ms]   BSD 盲区逻辑 (遍历目标, angle 分类)
  [4ms]   RCW 后碰撞预警 (高速目标筛选)
  [6ms]   转向辅助逻辑 (如打灯中, 同侧危险判断)
  [8ms]   LED 闪烁状态机 (每 667ms 翻转 = 1.5Hz)
  [10ms]  蜂鸣器状态机
  [12ms]  串口调试输出 (每 500ms)
  [50ms]  循环延时
```

---

## 5. 安装指南

### 5.1 雷达安装位置 (关键)

```
                    ┌───── 车头 ─────┐
                    │                │
                    │    仪表盘      │
                    │(ESP32+电路盒)  │
                    │                │
            ┌───────┤                ├───────┐
            │       │    坐垫         │       │
            │       │                │       │
            │       └────────────────┘       │
            │                                 │
    左后───┤         单雷达居中            ├───右后
    LED    │     (朝正后方, 安装在车尾)      │    LED
           │                                 │
           └─────────────────────────────────┘
```

**雷达安装要求（严格，否则角度判不准）：**
- ✅ **居中安装**，在车尾部（后挡泥板或货架）正中央
- ✅ 天线面朝 **正后方**，与车体纵轴平行（0° 偏差）
- ✅ 安装高度 **0.5~1.5m**（电瓶车推荐 0.7~0.9m）
- ✅ 前方（天线面朝向的反方向）**绝对净空**，无金属遮挡
- ❌ 不能歪斜安装——角度偏移会导致左/右分区漂移
- ❌ 雷达天线前不能有金属牌照架、车筐等

> **为什么必须居中朝正后方？**
>
> 因为 angle 值的参考系是雷达法线。只有雷达法线 = 车体纵轴时，
> angle < 0 才准确对应车辆左侧，angle > 0 对应右侧。
> 如果雷达偏左或偏右安装，角度分区会发生系统性偏移。

**转向灯安装：**
- 前转向灯：安装在车把左右两侧或前叉上，用自带金属支架 + M6 螺丝固定
- 后转向灯：安装在坐垫后方的车架两侧
- 转向灯线头引出后接硅胶延长线，接头务必防水（热缩管+硅胶密封）

### 5.2 电路盒安装

- 防水盒固定在车篮下方或座桶内
- ESP32 + XL7015 + AMS1117 + MOSFET + 蜂鸣器均置于盒内
- 盒体侧面开孔穿线，出线口用防水接头
- 雷达模块建议外置于车尾货架处（天线不能有金属遮挡）

### 5.3 电气安全注意事项

1. **48V 高压务必先接保险丝**（5A 慢熔保险，紧贴电瓶正极）
2. **XL7015 输入电容** 220μF/63V，输出电容 100μF/25V（模块自带则不用外加）
3. **所有大功率地线星型汇接**，避免回路干扰
4. **UART 线材**使用屏蔽线或用双绞线，远离 48V 电源线
5. **转向灯负极**接 MOSFET 漏极，不是直接接地
6. **雷达 3.3V 供电**单独从 AMS1117 取电，不要从 ESP32 板载 3.3V 取电
7. **焊接完成先目测检查**，再用万用表测通断和短路，最后才通电

---

## 6. 分步焊接调试指南

遵循 **先核心后外围** 原则，每焊完一个子系统立即测试，避免全部焊完后排查问题。

### 6.1 第一阶段：ESP32 + 雷达（最小系统）

**目标：** 验证雷达通讯、目标探测、角度判左右。无需 48V 电瓶、MOSFET、LED 等任何外围器件。

#### 物料准备

| 物料 | 数量 | 备注 |
|---|:--:|---|
| ESP32 开发板 | 1 | 已烧录固件 |
| MS60-3015 雷达 | 1 | BSD 版本 |
| 杜邦线 母-母 | 4 根 | 用于 ESP32 ↔ 雷达 |
| USB 数据线 | 1 | 供电 + 串口调试 |
| 热缩管 φ2mm | 4 段 | 雷达引脚绝缘 |
| 电烙铁 + 焊锡 | — | 雷达邮票孔焊接 |

#### 雷达引脚定义

```
MS60-3015S80M4 (俯视图, 天线面朝上, 邮票孔朝自己)

     ┌──────────────────────┐
     │   ████████████████   │  ← 天线面 (60GHz)
     │   ██  MS60-3015  ██  │
     │   ████████████████   │
     │                      │
     │ ①  ②  ③  ④  ⑤     │  ← 5pin 邮票孔 (半圆缺口)
     └──────────────────────┘
      3.3V GND OUT RX  TX
```

| 引脚 | 标识 | 连接 ESP32 | 说明 |
|:---:|---|---|---|
| ① | **3.3V** | 3.3V | 供电 50mA+（**切勿接 5V**） |
| ② | **GND** | GND | 共地 |
| ③ | OUT | **悬空** | GPIO 输出（本方案不用） |
| ④ | **RX** | GPIO17 | 雷达接收（ESP32→雷达） |
| ⑤ | **TX** | GPIO16 | 雷达发送（雷达→ESP32） |

### 雷达命令码 (AT6010官方, §3.2, 2026-07-05确认)

| 命令 | 编码 | 说明 |
|---|---|---|
| 雷达开关 | 0xD1 | §3.2.1 |
| 运动检测灵敏度 | 0x35 | §3.2.11, 0-10, 越小越灵敏 |
| 运动最远距离 | 0xD2 | §3.2.9, u16 cm |
| 保存Flash | 0x05 | §3.1.5, 需1秒延迟 |
| 查询版本 | 0xFE | §3.1.10 |

> ⚠️ 校验和为1字节 (HEAD+CMD+LEN+PARAMS 的和), 不是2字节

#### 接线图

```
     ESP32 DevKit                    MS60-3015
┌──────────────────┐          ┌──────────────────┐
│                  │          │                  │
│  3.3V ──────────┼──────────┤ ① 3.3V           │
│  GND  ──────────┼──────────┤ ② GND            │
│                  │          │ ③ OUT (悬空)     │
│  GPIO17(TX2) ───┼──────────┤ ④ RX             │
│  GPIO16(RX2) ───┼──────────┤ ⑤ TX             │
│                  │          │                  │
│  USB ──── 电脑   │          └──────────────────┘
└──────────────────┘
```

#### 焊接要点

1. **先给雷达引脚上锡**：5 个邮票孔半圆缺口，烙铁 320°C，每个点 1~2 秒即可
2. **杜邦线剥头 3mm 上锡**，焊到对应引脚上
3. **每个焊点套热缩管**，防止相邻引脚短路（引脚间距仅 1.27mm）
4. **用万用表蜂鸣档**测相邻引脚是否短路，再通电
5. 天线面（有 MS60-3015 丝印的一面）**朝正后方**，前方无金属遮挡

#### 上电测试

USB 插电脑后，打开串口监视器（115200bps），预期输出：

``` 
=== e-Bike BSD Turn Signal System (V2.2) ===
Hardware: ESP32 + MS60-3015 ×1 (居中安装)
[RADAR] 初始化雷达 (UART2, GPIO16/17, 921600bps)...
[RADAR] BSD模式已设置
=== 系统就绪 ===
=== [5] RX:0 TURN:OFF | BSD:0tgt ! | BZ:0 | TURN:OFF | IND:-
 (雷达无目标时静默 — 协议规定)
```

**挥手测试：** 手掌在雷达天线面正后方 0.5~3m 处挥动：

```
=== [42] TURN:OFF | BSD:1tgt L* [1m,-25°,2m/s,ID3] | BZ:1 | TURN:OFF | IND:- | DIR:L
```

| 通过标准 | 验证项 |
|---|---|
| `[RADAR] 雷达 UART OK` | UART 通讯正常 |
| `BSD模式已设置` | 雷达正确配置为 BSD 模式 |
| `BSD:1tgt` (挥手时) | 雷达探测到目标 |
| `L*` 在左侧挥手 / `R*` 在右侧 | 角度判左右正确 |
| 距离 1~3m 合理 | 测距准确 |

**常见故障：**

| 现象 | 可能原因 | 解决 |
|---|---|---|
| `雷达初始化失败` | TX/RX 接反或虚焊 | 交换 GPIO16/17，补焊 |
| 一直 `BSD:0tgt` | 天线面前有金属遮挡 | 移开金属物 |
| 串口无输出 | 波特率不对 | 确认 115200 |
| 雷达发热严重 | 接了 5V | **立即断电**，接回 3.3V |

---

### 6.2 第二阶段：MOSFET + 转向灯

*（待第一阶段通过后）*

接线内容：4 个 IRLZ44N + 4 个 12V LED 转向灯 + 12V 电源（可用 12V 适配器临时供电，暂不接 48V 降压）

### 6.3 第三阶段：开关 + 蜂鸣器 + 指示灯

*（待第二阶段通过后）*

接线内容：三档开关（GPIO13/14）+ 双闪按钮（GPIO27）+ 蜂鸣器（GPIO12）+ 指示灯 LED（GPIO25/26）

### 6.4 第四阶段：48V 电源系统

*（待第三阶段通过后）*

接线内容：XL7015 降压模块 + AMS1117 + 保险丝 + 电瓶接线

---

## 7. 调试方法（完整系统）

| 步骤 | 操作 | 预期结果 |
|:----:|---|---|
| 1 | 接通 48V 电源 | ESP32 启动，串口输出 "=== e-Bike BSD Turn Signal System (V2.1) ===" |
| 2 | 等待 5s | 雷达建立探测，串口显示 obj_num > 0 |
| 3 | 左转开关推到左位 | 左前+左后 LED 同步 1.5Hz 闪烁 |
| 4 | 右转开关推到右位 | 右前+右后 LED 同步 1.5Hz 闪烁 |
| 5 | 站车后方左侧 3m 挥手 | 串口显示 L*, 蜂鸣器短鸣一次 |
| 6 | 站车后方右侧 3m 挥手 | 串口显示 R*, 蜂鸣器短鸣一次 |
| 7 | 打左灯 + 在左侧挥手模拟接近 | 左指示灯常亮 + 蜂鸣长鸣, 转向灯保持 1.5Hz 正常闪烁 |
| 8 | 右转开关推回中位 | 右转向灯熄灭 |
| 9 | USB 连接电脑 | 串口监视器 115200bps 输出调试数据 |

### 调试串口输出示例

```
=== [42] TURN:L | BZ:2 | TURN:ON | IND:L | RCW-L | BSD:2tgt L* [8m,-28°,4m/s,ID1] [12m,+10°,3m/s,ID2] | DIR:L C
```

解读：
- `TURN:L` = 左转向灯亮着
- `BZ:2` = RCW 4Hz 蜂鸣
- `BZ:3` = 转向辅助长鸣
- `TURN:ON` = 转向灯LED当前亮
- `IND:L` = 左指示灯常亮
- `RCW-L` = 左后方快车预警
- `BSD:2tgt L*` = 2个目标，左侧盲区有目标报警
- `[8m,-28°,4m/s,ID1]` = 目标1: 距离8m, 角度-28°(左后方), 速度4m/s(接近)
- `[12m,+10°,3m/s,ID2]` = 目标2: 距离12m, 角度+10°(正后方偏右), 速度3m/s
- `DIR:L C` = 角度方向: 左, 中

---

## 8. platformio.ini 参考配置

```ini
[env:esp32dev]
platform = espressif32
board = esp32dev
framework = arduino
monitor_speed = 115200
board_build.flash_mode = qio
board_build.partitions = default_ffat.csv

; 如果使用 OLED, 取消以下注释:
; build_flags = -DENABLE_OLED
; lib_deps = 
;     adafruit/Adafruit SSD1306@^2.5.7
;     adafruit/Adafruit GFX Library@^1.11.5
```

---

---

## 8.5 钥匙开关控制 (3.3V信号 → 48V电源通断)

电瓶车钥匙开关输出的 **3.3V 信号**，通过 P-MOSFET 高边开关控制 BSD 系统 48V 主电源。

### 电路

```
                 48V+ ──→ IRF9540 S ── D ──→ XL7015输入 (BSD系统)
电瓶48V+ ────────────────┘         │
                                   G ──┬── R1(47kΩ) ── S8050 C
                                   │   │              E ── GND
                                   │   │              B ── R3(10kΩ) ── 钥匙3.3V
                                   │   │
                                   │   └── R2(10kΩ) ── 48V+ (S极)
                                   │
电瓶48V- ───────────────────────────┴── GND
```

### 工作原理

| 钥匙状态 | S8050 | IRF9540 G极电压 | Vgs | MOSFET |
|:--|:--|--:|--:|:--:|
| OFF (0V) | 截止 | 48V (R2上拉) | 0V | **关断** |
| ON (3.3V) | 导通 | 39.6V (R1/R2分压) | **-8.4V** | **导通** |

3.3V 控制 48V——小信号控大电流。钥匙电流仅 0.26mA，不增加原车电路负担。

**Vgs 恒在 -9.5V~-7.4V（电池满电 54V~亏电 42V），远低于 IRF9540N 的 ±20V 极限。**

### 元器件

| 元件 | 型号 | 封装 | 数量 | 淘宝 |
|---|---|---|:--:|---|
| P-MOSFET | **IRF9540N** | TO-220 | 1 | ¥2 |
| NPN 三极管 | **S8050** | TO-92 | 1 | ¥0.5 |
| 电阻 | **47kΩ 1/4W** | AXIAL-0.3 | 1 | ¥0.1 |
| 电阻 | **10kΩ 1/4W** | AXIAL-0.3 | 2 | ¥0.2 |

**总成本: ¥3。** 不需要继电器，不需要额外降压模块。

### 接线步骤

1. 找到钥匙 ON 后有 3.3V 的那根线
2. 3.3V → 10kΩ(R3) → S8050 B
3. S8050 E → GND
4. S8050 C → 47kΩ(R1) → IRF9540 G
5. IRF9540 G → 10kΩ(R2) → IRF9540 S (也是 48V+)
6. IRF9540 S → 电瓶 48V+
7. IRF9540 D → BSD 系统输入

---

## V2.5 升级日志 (2026-07-04)

### 🐛 修复

| 问题 | 根因 | 修复 |
|---|---|---|
| RCW/BSD LED 闪烁冲突 | `updateBSD()` 每循环写 LOW → RCW 只在新帧写 HIGH，BSD 覆盖 RCW | BSD 写 LED 前检查 `!rcw_*_active` |
| 关转向重开后误报 | `updateTurnAssist()` 缺少帧新鲜度检查，用旧帧数据重复触发 | 加 `static last_ts_turn` + 跳过旧帧 |
| 转向辅助蜂鸣断续 | 之前用 3Hz 脉冲 (`buzzer_mode=2`)，与 RCW 冲突 | 新增 `buzzer_mode=3` 持续长鸣 |
| 关转向后蜂鸣残留 | 清楚逻辑只检查 `buzzer_mode==2`，遗漏 mode 3 | 所有清除点改为 `==2 || ==3` |
| 关转向后 LED 残留 | 主循环 else 分支未清除指示灯 | 加 `digitalWrite(LOW)` 逻辑 |

### 🔧 改进

| 项目 | 旧行为 | 新行为 |
|---|---|---|
| BSD LED | 灭（仅蜂鸣） | **1Hz 慢闪**（提醒级，一眼看出侧方有车） |
| RCW LED | 常亮（与BSD同） | **4Hz 快闪**（危险级，与蜂鸣同步，无法忽视） |
| 转向辅 LED | 常亮 | **常亮**（警告级，专注判断是否变道） |
| 转向辅助蜂鸣 | 3Hz 断续 | **持续长鸣**（更明确："危险！"） |
| LED 控制 | 各函数直接 digitalWrite | **集中状态机 updateIndicatorLEDs()**（防冲突） |
| 指示灯模式 | 无区分 | **4 模式**（OFF/BSD 1Hz/RCW 4Hz/TURN 常亮） |
| RCW 距离阈值 | 20m | **25m**（与主力固件一致） |
| RCW 速度阈值 | 14.4 km/h | **10.8 km/h**（3 m/s） |
| 蜂鸣器模式 | 0/1/2 三级 | **0/1/2/3 四级**（BSD/RCW/转向辅独立） |

### ✅ 已烧录 (V2.7)

所有修复已通过编译验证并烧录至 ESP32 (V2.7)。

## V2.7 升级日志 (2026-07-06)

### 🔥 重大变更

| 项目 | 旧行为 | 新行为 |
|---|---|---|
| WiFi 自动关 | sta>0 时重置计时器(Bug: 幽灵站导致永不关) | **二态状态机**: 有连接清零计时 / 无连接累计 → 30s关; 断开后重新30s倒计时 |
| WiFi 关闭序列 | WiFi.softAPdisconnect + WiFi.mode(WIFI_OFF) | **增加 WiFi.enableAP(false) + delay(50)** 确保 AP 信标彻底停止 |
| 雷达目标残留 | 目标消失后红点永远留在可视化区 | **checkStale(500ms)**: 500ms无新BSD帧 → obj_num清零, 前端自动清除 |
| 配置保存 | saveToNVS 不检查写结果, 静默失败 | **检查 putString 返回值 + 串口打印保存JSON**, POST handler 检查 saveToNVS 返回值 |
| StaticJsonDocument | 函数栈上分配 4KB/8KB → 栈溢出 | **static 修饰符** → BSS段分配, 无栈风险 |
| ArduinoJson API | add<JsonObject>() (已废弃) | **createNestedObject()** (6.x兼容) |
| 构建系统 | 无库依赖声明 | **platformio.ini 明确依赖**(ArduinoJson 6.21, AsyncTCP, AsyncWebServer) |
| BSD 参数组 | BSDParams 独立存在(7字段), V2.6已与RCW合并但未清理 | **彻底删除 BSDParams 结构体 + toJson/fromJson BSD分支**, ANGLE_IS_* 改读 config.rcw |
| NVS 清理 | 残留 V2.5 旧格式(profile字段, 缺失6个RCW字段) | **出厂重置清空旧NVS + erase_region 彻底擦除** |

### 🔧 改进

| 项目 | 说明 |
|---|---|
| 串口命令 | 新增 `RESET`(出厂重置), `DUMP`(打印完整JSON配置) |
| WiFi串口调试 | 每2秒输出 `[WIFI] sta=N idle=Xs` 方便诊断 |
| 可视化信息栏 | stale 后显示"无目标"而非"帧无效"(`valid` 保持 true) |
| 编译警告 | `isInLeftTurnZone/isInRightTurnZone` 补上 return 语句, 无警告零错误 |
| 空闲检测精度 | 检查间隔从 5s → 2s, 断开响应更快 |
| 配置字段 | 从 28 字段(含废弃BSD)精简为 **21 字段** (RCW 10 + TURN 6 + SYS 3 + RADAR 2) |
| factoryReset | 同时重置 sys 参数组(之前遗漏) |

### 🖥️ C3 触摸显示面板 (新增)

| 项目 | 说明 |
|---|---|
| 硬件 | ESP32-C3 (立创实战派) + ST7789 320x240 + FT6336 触摸 |
| 显示屏 | 全屏120°雷达扇形图, 4条距离弧线, ±40°虚线边界 |
| 目标显示 | 实时红点 + 速度标签 (m/s), 每秒5次更新 |
| 配置界面 | 4页触摸参数设置 (RCW1/RCW2/TURN/SYS) |
| 参数调整 | +/- 大按钮, 字体大小2, 防误触 |
| WiFi 控制 | SYS页 ON/OFF 按钮, 远程开关 ESP32 WiFi |
| 配置同步 | REFRESH 按钮从 ESP32 读取当前参数 |
| SAVE->ESP | 保存配置到 ESP32 NVS, 大字 SAVED! 确认 |
| 通信协议 | UART1 115200bps, GPIO18/19 双向通信 |
| 数据包格式 | 心跳包(AA FF bsd rcw bz turn 55) + 目标包(AA NN angle range velo×N 55) |
| 配置协议 | $CFG(保存), $GETCFG(请求), $WIFI(开关) |
| **连接状态指示** | **屏幕左上角绿点ON/红点LOST, 基于ESP32心跳包(>1.5s无数据=断开)** |
| SPI | 硬件SPI (SCLK=3,MOSI=5), 速度快 |
| I2C | 触摸FT6336 (SDA=0,SCL=1, ADDR=0x38) |

### 📁 文件变更

| 文件 | 变更 |
|---|---|
| `ebike_bsd.ino:#166-#207` | WiFi 自动关状态机重写 |
| `ebike_bsd.ino:#213` | 新增 `radar.checkStale(500)` 调用 |
| `ebike_bsd.ino:#252-#266` | 新增 RESET/DUMP 串口命令 |
| `ms60_radar.h:#186` | 新增 `checkStale()` 方法 |
| `wifi_web.h:#39` | `add<JsonObject>()` → `createNestedObject()` |
| `wifi_web.h:#295-#310` | POST handler 加调试日志 + saveToNVS 返回值检查 |
| `bsd_protocol.h:#138` | `isInLeftTurnZone/isInRightTurnZone` 补全实现 |
| `config_store.h` | **删除 BSDParams 结构体**(14行), StaticJsonDocument 加 static, fromJson/toJson/summary/factoryReset 清理, saveToNVS 加错误检查 |
|| `c3-display/test_uart.ino` | **新增连接状态指示: 左上角绿点ON/红点LOST 基于ESP32心跳超时1.5s** |
|| `docs/DESIGN.md` | C3表格新增连接状态指示说明, 更新日期 |

## V2.6 升级日志 (2026-07-05)

### 🔥 重大变更

| 项目 | 旧行为 | 新行为 |
|---|---|---|
| BSD+RCW | 两个独立系统(updateBSD+updateRCW) | **合并为统一后方监测**(updateRCW两级判断) |
| 速度判断 | `abs(velocity)` 绝对值 | **有符号判断** (仅靠近目标触发) |
| 距离字段 | 固定1m(伪造) | **真实雷达距离**(s8,m) |
| 速度字段 | int16_t 2字节(错位) | **s8 1字节**(正确,4B格式) |
| 转向灯驱动 | 4路GPIO(前后分开) | **2路GPIO**(同侧并联) |
| 双闪功能 | 独立按钮+HAZARD状态 | **已移除** |
| 雷达命令 | 0x02(无效)/校验和2B | **0x35/0xD2/0x05**(正确AT6010)+校验和1B |
| WiFi | 常开 | **30秒无人连自动关**(V2.7修复状态机), 下次开机重开 |
| 看门狗 | setup超时重启 | **setup禁用/loop启用** |

### 🔧 改进

| 项目 | 说明 |
|---|---|
| 角度系统 | 后方监测用 REAR_ANGLE_IS_LEFT/RIGHT, 转向辅用 TURN_ANGLE_IS_LEFT/RIGHT, 各自独立可配 |
| 帧格式 | 确认MS60-3015使用官方4字节格式, 校验和验证通过 |
| LED分级 | 低速→IND_MODE_BSD(1Hz), 高速→IND_MODE_RCW(4Hz), 低速蜂鸣5秒冷却 |
| 雷达配置 | Flash持久化(0x05命令), 灵敏度范围0-10, 距离单位cm→m换算 |
| 引脚安全 | GPIO5/15→GPIO23/27 解决启动冲突 |

---

## 9. 安全免责声明

> 本系统为 DIY 自制辅助设备，**不能替代**骑车人自己观察判断。转向灯/盲区检测/转向辅助均为辅助功能，骑行时仍需自行观察路况，确认安全后方可转向。作者不对因使用本系统造成的任何事故损失承担责任。

---

## 10. 参考链接

- [觅感科技 MS60-3015 产品手册 (PDF)](https://itemcdn.tmall.com/attachment/icoss165317425452993e4899af54db)
- [ESP32 Arduino 核心文档](https://docs.espressif.com/projects/arduino-esp32/)
- [IRLZ44N 数据手册](https://www.infineon.com/dgdl/irlz44npbf.pdf)

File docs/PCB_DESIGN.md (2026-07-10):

# e-Bike BSD 系统 PCB 设计规格书 V2.7

## 1. 板级参数

| 参数 | 值 |
|---|-----|
| PCB 尺寸 | 80mm × 60mm (双面板) |
| 铜厚 | 1oz |
| 板厚 | 1.6mm |
| 最小线宽 | 0.3mm (信号) |
| 最小间距 | 0.3mm |
| 表面处理 | HASL 有铅 |

## 2. 电路模块

```
┌─────────────────────────────────────────────┐
│  J1 48V输入  │ XL7015 48→12V │ 12V输出 J2   │
│  F1 保险丝   │   模块区域    │              │
├──────────────┴───────────────┴──────────────┤
│             LM2596 12→5V                    │
│             5V输出                          │
├─────────────────────────────────────────────┤
│  ┌──────────────────────────────────┐       │
│  │         ESP32-DevKitC            │       │
│  │         排母插座 (2×19)           │       │
│  └──────────────────────────────────┘       │
│                                             │
│  Q1-Q2: IRLZ44N ×2 (TO-220 卧装)            │
│  R1-R2: 100Ω 1/4W ×2                       │
│  RPD1-RPD2: 10kΩ 1/4W ×2                   │
│                                             │
│  J3: MS60-3015 雷达 (5pin 2.54排针)         │
│  J4: 蜂鸣器 (3pin)                          │
│  J5: 转向开关 (4pin)                        │
│  J6: C3显示面板 (4pin)                      │
│  J7: 转向灯输出 (4pin 5.08mm端子)           │
│  D1-D2: RCW LED (5mm 焊盘)                  │
└─────────────────────────────────────────────┘
```

## 3. 完整网络表 (V2.7)

### 电源网络

| 网络名 | 连接 |
|---|---|
| `+48V` | J1.1 → F1.1 |
| `+48V_F` | F1.2 → XL7015 IN+ |
| `+12V` | XL7015 OUT+ → LM2596 IN+ → J2.1 → 转向灯阳极 |
| `+5V` | LM2596 OUT+ → ESP32 5V → J3.1 (雷达) → J4.1 (蜂鸣器) |
| `+3.3V` | ESP32 3V3 (板载) |
| `GND` | 所有模块共地 |

### 信号网络

| 网络名 | 起点 | 终点 | 说明 |
|---|---|---|---|
| `RADAR_TX` | J3.5 (雷达TX) | ESP32 GPIO16 | 雷达→ESP32 |
| `RADAR_RX` | ESP32 GPIO17 | J3.4 (雷达RX) | ESP32→雷达 |
| `LED_LEFT_GATE` | ESP32 GPIO4 | R1→RPD1→Q1.G | 左转向MOSFET栅极 |
| `LED_RIGHT_GATE` | ESP32 GPIO23 | R2→RPD2→Q2.G | 右转向MOSFET栅极 |
| `LED_LEFT_OUT` | Q1.D | J7.1 (左灯-) | 左前+左后并联 |
| `LED_RIGHT_OUT` | Q2.D | J7.2 (右灯-) | 右前+右后并联 |
| `+12V_LAMP` | J2.1 | J7.3, J7.4 (灯阳极) | 转向灯共用12V |
| `BUZZER` | ESP32 GPIO12 | J4.3 (I/O) | 蜂鸣器信号 |
| `RCW_L` | ESP32 GPIO25 | R5→D1+ | 左RCW LED |
| `RCW_R` | ESP32 GPIO26 | R6→D2+ | 右RCW LED |
| `SW_LEFT` | ESP32 GPIO13 | J5.1→GND | 左转开关 (按下=低) |
| `SW_RIGHT` | ESP32 GPIO14 | J5.2→GND | 右转开关 (按下=低) |
| `U1_TX` | ESP32 GPIO18 | J6.2 (C3 RX) | C3显示面板发送 |
| `U1_RX` | ESP32 GPIO19 | J6.1 (C3 TX) | C3显示面板接收 |

### 转向灯接线 (外部)

| 端子 | 信号 | 说明 |
|---|---|---|
| J7.1 | LED_LEFT_OUT (Q1.D) | 左前+左后灯 负极 |
| J7.2 | LED_RIGHT_OUT (Q2.D) | 右前+右后灯 负极 |
| J7.3 | +12V | 所有转向灯正极共用 |
| J7.4 | +12V | 所有转向灯正极共用 |

> 同侧前后灯并联：左前灯(-) + 左后灯(-) → 一起接到 J7.1
> 右前灯(-) + 右后灯(-) → 一起接到 J7.2
> 所有灯的正极 → +12V 母线 (J7.3 或 J7.4)

## 4. 元器件清单 (BOM)

### 功率模块

| 编号 | 型号 | 封装 | 数量 | 说明 |
|---|---|---|:--:|---|
| U1 | XL7015 | 模块(4P排针) | 1 | 48V→12V 3A |
| U2 | LM2596 | 模块(4P排针) | 1 | 12V→5V 2A |
| F1 | 保险丝座 5×20 | 插件 | 1 | + 3A 慢熔保险管 |

### MOSFET

| 编号 | 型号 | 封装 | 数量 | 说明 |
|---|---|---|:--:|---|
| Q1-Q2 | IRLZ44N | TO-220 | 2 | 逻辑电平 N-MOSFET |

### 电阻

| 编号 | 阻值 | 封装 | 数量 | 说明 |
|---|---|---|:--:|---|
| R1-R2 | 100Ω | 0805 | 2 | MOSFET 栅极限流 |
| RPD1-RPD2 | 10kΩ | 0805 | 2 | 栅极下拉 |
| R5-R6 | 220Ω | 0805 | 2 | RCW LED 限流 |

### 连接器

| 编号 | 类型 | 针数 | 说明 |
|---|---|:--:|---|
| J1 | 5.08mm 接线端子 | 2 | 48V 输入 |
| J2 | 5.08mm 接线端子 | 2 | 12V 输出 |
| J3 | 2.54mm 排针 | 5 | 雷达 (VCC/GND/OUT/RX/TX) |
| J4 | 2.54mm 排针 | 3 | 蜂鸣器 (VCC/GND/I/O) |
| J5 | 2.54mm 排针 | 4 | 转向开关 (L/R/H/GND) |
| J6 | 2.54mm 排针 | 4 | C3面板 (GND/TX/RX/VCC) |
| J7 | 5.08mm 接线端子 | 4 | 转向灯输出 (左-/右-/12V/12V) |
| H1 | 2.54mm 排母 | 2×19 | ESP32-DevKitC 插座 |

### 指示灯

| 编号 | 型号 | 封装 | 数量 |
|---|---|---|:--:|
| D1-D2 | 5mm 红色 LED | 插件 | 2 |

## 5. 布局建议

```
顶层 (布线区):
  ┌──────────────────────────────────────┐
  │ [J1] [F1] [U1 XL7015]  [J2]         │ ← 高压区 (48V/12V)
  │ ─────────────────────────────────── │
  │        [U2 LM2596]                   │ ← 5V转换
  │ ─────────────────────────────────── │
  │   [J3雷达] [J4蜂鸣] [J6 C3]          │ ← 信号区
  │                                      │
  │ ┌────────────────────┐  [J5开关]    │
  │ │ ESP32 38P 排母     │              │
  │ └────────────────────┘  [J7转向灯]  │
  │                                      │
  │ [Q1] [Q2]    [D1 D2]  [R..]         │ ← 功率+指示区
  └──────────────────────────────────────┘
```

## 6. 布线规则

| 网络类型 | 线宽 | 说明 |
|---|:----:|---|
| +48V 主电源 | **3.0mm** | 顶层, 到保险丝 |
| +12V 母线 | **1.5mm** | 顶层 |
| +5V 母线 | **1.0mm** | 顶层 |
| MOSFET D-S (灯路) | **1.0mm** | 顶层 |
| 信号线 (GPIO) | **0.3mm** | 顶层优先 |
| GND | 铺铜 | 底层完整铜皮 + 顶层周边 |

## 7. 制作步骤

1. 打开 [KiCad 8.0](https://www.kicad.org/download/) → 打开 `kicad/ebike-bsd.kicad_pro`
2. 检查原理图网络连接
3. PCB 布局 → 自动布线 → 手动调整
4. DRC 检查 → 制造输出 → Gerber
5. 提交嘉立创打样

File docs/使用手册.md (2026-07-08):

# 电动自行车进阶转向灯+盲区监测系统 — 安装与使用手册

**版本:** V2.7 | **日期:** 2026-07-07 更新 | **适用车辆:** 48V 电瓶电动自行车

---

### V2.7 核心特性 (含V2.6)

| 特性 | 说明 |
|---|---|
| WiFi自动关 | 30秒无连接→关闭射频省电; 有连接保持; 断开后重新30s倒数 [V2.7] |
| 后视镜可视化 | 本车在底部, 目标按角度+距离分布在扇形区域内 |

| 特性 | 说明 |
|---|---|
| **后方监测 (BSD+RCW合并)** | 统一后方监测, 按速度两级报警 (低≥1m/s慢闪, 高≥4m/s快闪) |

| 特性 | 说明 |
|---|---|
| 后方监测 | 角度+距离+速度三维判定, 两级报警 |
| RCW碰撞预警 | 快目标(>3m/s)+近距离(<25m)同时满足 |
| 转向辅助 | 开转向灯时检测同侧快目标 |
| WiFi控制 | 每次开机30秒无人连自动关; C3触摸屏可强制开关 | [V2.7]
| 雷达持久化 | 配置写入雷达Flash, 断电不丢 |
| **距离+速度显示** | 控制台实时显示目标距离(m)和速度(m/s) |
| **官方4B帧格式** | 校验和已验证, 距离/角度/速度全解码 |

## 目录

1. [系统简介](#1-系统简介)
2. [硬件清单](#2-硬件清单)
3. [安装步骤](#3-安装步骤)
4. [接线图](#4-接线图)
5. [首次开机](#5-首次开机)
6. [灯和声音说明](#6-灯和声音说明)
7. [日常使用](#7-日常使用)
8. [故障排查](#8-故障排查)
9. [安全须知](#9-安全须知)

---

## 1. 系统简介

### 你装了什么

| 功能 | 是什么 | 有什么用 |
|---|---|---|
| **转向灯** | 前后左右 4 个 LED 灯条 | 告诉后车你往哪转 |
| **BSD 盲区监测** | 毫米波雷达 + 红色指示灯 | 侧后方有车时 LED 亮，提醒你 |
| **RCW 后碰撞预警** | 雷达 + 蜂鸣器 | 后方车快速逼近时蜂鸣大叫 |
| **转向辅助** | 雷达 + 指示灯 + 蜂鸣器 | 打转向灯时自动判断该方向安不安全 |

### 核心器件

```
[48V 电瓶] → [XL7015降压12V] → [LM2596降压5V] → [ESP32 主控]
                                                      ├── [MS60-3015 雷达]
                                                      ├── [MOSFET ×4] → [4个转向灯]
                                                      ├── [2个红色指示灯]
                                                      └── [蜂鸣器]
```

### 雷达覆盖范围

```
        左后方 ← ← ← ← ← → → → → 右后方
        ──────────────────────────────────
盲区:    [-40°════-15°] [正后] [+15°════+40°]
碰撞:    [-40°════════-5°] [+5°════════+40°]
         ← 有车 LED亮       有车 LED亮 →
```

- 正后方 ±14° 不报警（你能从后视镜看到）
- 最大探测距离：汽车 50m，实测有效 ~30m
- 不检测远离你的车

---

## 2. 硬件清单

### 必买器件

| # | 名称 | 型号/搜索词 | 数量 | 单价 | 用途 |
|---|---|---|:---:|-----|---|
| 1 | ESP32 开发板 | `ESP32 DevKitC 30pin` | 1 | ¥25 | 主控 |
| 2 | 毫米波雷达 | `MS60-3015 60GHz` | 1 | ¥60 | 探测后方来车 |
| 3 | 转向灯（前） | `摩托车LED转向灯 12V 琥珀色` | 2 | ¥15 | 车前转向信号 |
| 4 | 转向灯（后） | `摩托车LED转向灯 12V 琥珀色` | 2 | ¥15 | 车后转向信号 |
| 5 | DC-DC 降压模块 | `XL7015 DC-DC 降压 48V→12V` | 1 | ¥8 | 电瓶稳压 |
| 6 | DC-DC 降压模块 | `LM2596 DC-DC 降压 12V→5V` | 1 | ¥8 | ESP32 供电 |
| 7 | MOSFET 驱动管 | `IRLZ44N TO-220` | 2 | ¥2 | 驱动 12V 转向灯 |
| 8 | 蜂鸣器 | `有源蜂鸣器 5V 12mm` | 1 | ¥3 | 声音报警 |
| 9 | 红色 LED | `5mm LED 红色 高亮` | 2 | ¥0.5 | 仪表指示灯 |
| 10 | 电阻 220Ω | `220Ω 1/4W 金属膜电阻` | 2 | ¥0.2 | LED 限流 |
| 11 | 转向开关 | `摩托车转向灯开关 三档` | 1 | ¥8 | 把手控制 |
| 12 | 13 | 杜邦线 | `母对母杜邦线 20cm` | 20根 | ¥3 | 接线 |
| 14 | 热缩管 | `热缩管套装 φ2-6mm` | 1套 | ¥5 | 绝缘 |
| 15 | 保险丝 | `汽车保险丝 5A 带座` | 1 | ¥2 | 过流保护 |
| 16 | 接线端子 | `2P/3P/5P 接线端子 2.54mm` | 各2 | ¥2 | 可插拔连接 |

> **总预算：约 ¥180-220**

### 工具

| 工具 | 用途 |
|---|---|
| 电烙铁 + 焊锡 | 雷达邮票孔焊接 |
| 万用表 | 测电压、通断 |
| 热熔胶枪 | 固定线路 |
| 电工胶带 | 线束包裹 |
| 3M 双面胶 | 雷达/模块固定 |
| 扎带 | 线束整理 |

---

## 3. 安装步骤

### 3.1 安装前检查

1. 关掉电瓶电源
2. 万用表确认电瓶电压（正常 48-54V）
3. 所有器件摊开，对照清单清点

### 3.2 雷达焊接

雷达模块引脚很密（1.27mm 间距），**务必小心**：

```
MS60-3015 引脚定义（天线面朝上，邮票孔朝自己）：
 ┌─────────────────┐
 │  ██████████████  │ ← 天线面
 │  ██ MS60-3015 ██ │
 │  ██████████████  │
 │ ①  ②  ③  ④  ⑤  │ ← 5个半圆焊盘
 └─────────────────┘
 3.3V GND OUT RX  TX
```

| 引脚 | 接 ESP32 | 说明 |
|:---:|---|---|
| ① | 3V3 或 5V | 供电（两者都支持） |
| ② | GND | 地线 |
| ③ | 悬空 | 不用接 |
| ④ | **GPIO17** | 雷达接收（ESP32→雷达） |
| ⑤ | **GPIO16** | 雷达发送（雷达→ESP32） |

> ⚠️ 焊接要点：烙铁 320°C，每个焊点 1-2 秒。每个焊完的引脚套热缩管。焊完用万用表蜂鸣档测相邻引脚是否短路。

### 3.3 电源系统安装

```
电瓶 48V+ ──┬── 保险丝 5A ── XL7015 IN+
            │
电瓶 48V- ──┴────────────── XL7015 IN-

XL7015 OUT+ ── LM2596 IN+
XL7015 OUT- ── LM2596 IN-

LM2596 OUT+ ── ESP32 5V (VIN)
LM2596 OUT- ── ESP32 GND
```

> ⚠️ **XL7015 调试顺序**：先不接负载，万用表测输出调到 **12V**，再接后续电路。**LM2596 同理**，调到 **5V**。

### 3.4 转向灯安装

| 灯位 | 接 ESP32 | 驱动方式 |
|---|---|---|
| 前左 | GPIO4 (左前后并联) | IRLZ44N MOSFET |
| 前右 | GPIO23 | IRLZ44N MOSFET |
| 后左 | — (已合并到GPIO4) | IRLZ44N MOSFET |
| 后右 | — (已合并到GPIO23) | IRLZ44N MOSFET |

MOSFET 接线：
```
ESP32 GPIO ── 100Ω 电阻 ── IRLZ44N G (栅极)
转向灯+ ──── 12V 电源
转向灯- ──── IRLZ44N D (漏极)
IRLZ44N S (源极) ──── GND
```

### 3.5 开关安装

| 开关 | 接 ESP32 | 说明 |
|---|---|---|
| 左转 | GPIO13 | LOW=打左转 |
| 右转 | GPIO14 | LOW=打右转 |
| 双闪 | GPIO27 | 按下=双闪 |

把手三档开关（左-关-右），公共端 GND，左位接 GPIO13，右位接 GPIO14。

### 3.6 指示灯 + 蜂鸣器

| 器件 | 接 ESP32 | 说明 |
|---|---|---|
| 左指示灯 + | GPIO25 → 220Ω → LED+ → GND | 刹车灯式安装 |
| 右指示灯 + | GPIO26 → 220Ω → LED+ → GND | 视野余光可见 |
| 蜂鸣器 I/O | GPIO12 | 高电平触发 |

### 3.7 雷达安装位置

- 安装高度：离地 **0.5-1.5m**
- 天线面（有丝印的一面）**正对后方**
- 前方无金属遮挡
- 用 3M 双面胶 + 扎带固定

---

## 4. 接线图

```
                    ┌──────────────────────────────────┐
                    │              ESP32               │
                    │                                  │
   48V电瓶 ──XL7015──LM2596──→ 5V(VIN)              │
        GND ──────────────→ GND                      │
                    │                                  │
   雷达 ⑤脚 TX ──────────→ GPIO16                    │
   雷达 ④脚 RX ──────────→ GPIO17                    │
   雷达 ①脚 3.3V/5V ────→ 3V3/5V                   │
   雷达 ②脚 GND ────────→ GND                       │
                    │                                  │
   左转开关 ────────────→ GPIO13                     │
   右转开关 ────────────→ GPIO14                     │
   — (已移除, 无双闪功能)                     │
                    │                                  │
   蜂鸣器 I/O ──────────→ GPIO12                     │
                    │                                  │
   前左灯 MOSFET ──────→ GPIO4 (左前后并联)                       │
   前右灯 MOSFET ──────→ GPIO23                       │
   后左灯 MOSFET ──────→ — (已合并到GPIO4)                     │
   后右灯 MOSFET ──────→ — (已合并到GPIO23)                     │
                    │                                  │
   左指示灯 LED+ ──────→ GPIO25                      │
   右指示灯 LED+ ──────→ GPIO26                      │
                    └──────────────────────────────────┘
```

---

## 5. 首次开机

### 5.1 开机

1. 打开电瓶开关
2. 听到 **蜂鸣器 3 声短鸣** → 系统正常启动
3. 雷达自动初始化（约 3 秒后进入工作状态）

### 5.2 静态测试（不上路）

| # | 操作 | 预期 |
|---|---|---|
| 1 | 开机 | 蜂鸣 3 声 |
| 2 | 打左转 | 前左+后左灯 1.5Hz 闪烁 |
| 3 | 打右转 | 前右+后右灯 1.5Hz 闪烁 |
| 5 | 站车后左侧 ~3m，挥手 | 仪表**左 LED 亮** + 蜂鸣一声 |
| 6 | 站车后右侧 ~3m，挥手 | 仪表**右 LED 亮** + 蜂鸣一声 |
| 7 | 关转向 | 灯灭 |

---

## 6. 灯和声音说明

### 指示灯（车把红色 LED ×2）

| 场景 | 左灯 | 右灯 | 声音 | 含义 |
|---|:---:|:---:|:----:|---|
| 后方无车 | 灭 | 灭 | 无 | 安全 |
| 左侧盲区有车 | 🔴 **慢闪 1Hz** | 灭 | 滴一声 | 侧方来车，保持直行 |
| 右侧盲区有车 | 灭 | 🔴 **慢闪 1Hz** | 滴一声 | 侧方来车，保持直行 |
| 打左转 + 左侧有车 | 🔴 **常亮** | 灭 | 🔊 **长鸣** | 别变道！ |
| 打右转 + 右侧有车 | 灭 | 🔴 **常亮** | 🔊 **长鸣** | 别变道！ |
| 后方车快速逼近（左） | 🔴 **快闪 4Hz** | 灭 | 🔊🔊🔊 **4Hz** | **立即加速/靠边！** |
| 后方车快速逼近（右） | 灭 | 🔴 **快闪 4Hz** | 🔊🔊🔊 **4Hz** | **立即加速/靠边！** |
| 后方双侧快速逼近 | 🔴 **快闪 4Hz** | 🔴 **快闪 4Hz** | 🔊🔊🔊 **4Hz** | **极度危险！** |

> 💡 三种灯效一眼区分：慢闪=盲区有车（提醒），常亮=打转向但不安全（警告），快闪=后车急逼（危险）

### 蜂鸣器声音速查

| 声音 | 对应灯效 | 持续多久 | 意思 |
|---|:---:|---|---|
| "滴" 一声 | 慢闪 1Hz | 100ms | 有车进入盲区 |
| 4Hz 急促 | 快闪 4Hz | 车逼近期间 | **危险！后车快速逼近！** |
| 持续长鸣 | 常亮 | 关转向为止 | **你要转的方向有车！别变道！** |

### 紧急程度速查

| 系统 | 危急 | 灯 | 声音 | 你应该 |
|---|:---:|---|---|---|
| 低速接近 | ℹ️ | 🔴 1Hz 慢闪 | 冷却5秒后一声 | 保持直行，等车过去 |
| 转向辅助 | 🟡 | 🔴 **常亮** | 长鸣 | **不要变道！** 等灯灭 |
| RCW 碰撞 | 🔴 | 🔴 **4Hz 快闪** | 4Hz 蜂鸣 | **立即加速或靠边！** |

---

## 7. 日常使用

### 7.1 骑行前检查

1. 开机听 3 声短鸣 = 系统正常
2. 试打左右转向灯
3. 看一眼指示灯是否无故亮着

### 7.2 骑行中

- **指示灯慢闪 1Hz** = 侧方盲区有车，保持直行
- **指示灯快闪 4Hz + 蜂鸣 4Hz** = 后方车逼近，检查后视镜
- **打灯 + 蜂鸣长鸣** = 别变道，后方有车
- **灯灭了** = 安全，可操作

### 7.3 停车后

- 关电瓶
- 检查接线是否松动（尤其是雷达和 MOSFET 插头）
- 雨天骑行后擦干雷达天线面

---

## 8. 故障排查

| 现象 | 可能原因 | 怎么修 |
|---|---|---|
| 开机无反应 | 保险丝烧了 | 换 5A 保险丝 |
| 开机不叫 | 蜂鸣器线松了 | 检查 GPIO12 |
| 转向灯不亮 | MOSFET 坏或线松 | 万用表测 GPIO 输出电压 |
| 指示灯一直亮 | 有车一直在盲区 / 雷达被遮挡 | 检查雷达天线面是否被泥遮住 |
| 指示灯一直不亮 | 雷达线松了 | 检查 GPIO16/17 和供电 |
| 蜂鸣器不叫 | 蜂鸣器线松 | 检查 GPIO12，万用表测电压 |
| 雨天乱报 | 雷达天线面有水珠 | 擦干 |

> **完整调试**：把 ESP32 的 USB 口接电脑，用串口工具 115200bps 看日志。

---

## 9. 安全须知

> ⚠️ **本系统是辅助设备，不能替代你自己的眼睛和判断。**
>
> 1. 变道前**必须回头看一眼**，不要只依赖指示灯
> 2. 雷达**不检测正后方的车**（±14° 范围内），后视镜是你的责任
> 3. 雷达**不检测远离你的车**
> 4. 下雨、泥巴可能遮挡雷达天线，导致探测距离变短
> 5. 第一次上路选择车少的路段测试
> 6. 电瓶改装涉及 48V 高压，**断电操作**，接线牢固

---

## C3 触摸显示面板

C3 是一个独立的 ESP32-C3 显示模块, 通过杜邦线连接 ESP32 主控, 提供:
- **实时雷达可视化**: 120° 扇形图, 目标红点 + 速度
- **触摸参数设置**: 4页配置界面, 修改后保存到 ESP32
- **WiFi 开关**: 远程控制 ESP32 热点

### 接线

| ESP32 | → | C3 |
|---|---|-----|
| GPIO18 (TX) | → | GPIO19 (RX) |
| GPIO19 (RX) | ← | GPIO18 (TX) |
| GND | — | GND |

### 触摸操作

| 操作 | 方法 |
|---|---|
| 进入配置 | 雷达页右上角点 **SET** |
| 翻页 | 左上 **<** 或右上 **>** |
| 改参数 | 点参数旁的 **-** **+** |
| 保存到ESP32 | 底部 **SAVE->ESP** |
| 从ESP32读取 | 底部 **REFRESH** |
| 返回雷达 | 底部 **BACK** |
| WiFi 开关 | SYS 页最底部 **ON/OFF** |

### 参数页面

| 页 | 参数 |
|----|---|
| RCW 1/2 | LOW_V, HI_V, RANGE, HOLD, L_FLASH, H_FLASH |
| RCW 2/2 | BEEP_CD (蜂鸣冷却) |
| TURN | SPEED, RANGE, HOLD, FLASH |
| SYS | RAD_RNG, SENS, BEEP_CD, WiFi |

## 附录：固件烧录方法

当需要更新固件时：

1. 从车上取下 ESP32 模块
2. USB 数据线接电脑
3. 用 Arduino IDE 或命令行烧录（代码位于 `firmware/ebike_bsd.ino`）
4. 烧录完成听到 3 声短鸣 = 成功
5. 装回车上

---

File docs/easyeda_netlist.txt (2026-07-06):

# EasyEDA 导入用网表 (复制到 EasyEDA → 新建原理图 → 工具 → 导入网表)

# ============ 电源部分 ============
NET "48V_IN" = J1.1, F1.1
NET "48V_FUSED" = F1.2, XL7015.IN+
NET "GND_POWER" = XL7015.IN-, XL7015.OUT-, LM2596.IN-, LM2596.OUT-, J2.2, J6.2, J6.4, J6.6, J6.8
NET "+12V" = XL7015.OUT+, LM2596.IN+, J2.1
NET "+5V" = LM2596.OUT+, ESP32.5V, J3.1(J3引脚1=VCC), J4.1(J4引脚1=VCC)

# ============ ESP32 核心 ============
# ESP32 用标准 DevKitC 30pin 模块, 插入 2x15P 排母

# ============ 雷达 (J3, 5pin 2.54) ============
# J3.1=VCC→+5V, J3.2=GND, J3.3=OUT(悬空), J3.4=RX, J3.5=TX
NET "RADAR_TX" = J3.5, ESP32.GPIO16
NET "RADAR_RX" = J3.4, ESP32.GPIO17

# ============ 转向灯 (4路 IRLZ44N, 每路: GPIO→100Ω→G, D→灯-, S→GND) ============
NET "LED_FL_GATE" = ESP32.GPIO4, R1.1
NET "LED_FL_MOS" = R1.2, Q1.G
NET "LED_FL_OUT" = Q1.D, J6.1

NET "LED_FR_GATE" = ESP32.GPIO5, R2.1
NET "LED_FR_MOS" = R2.2, Q2.G
NET "LED_FR_OUT" = Q2.D, J6.3

NET "LED_RL_GATE" = ESP32.GPIO18, R3.1
NET "LED_RL_MOS" = R3.2, Q3.G
NET "LED_RL_OUT" = Q3.D, J6.5

NET "LED_RR_GATE" = ESP32.GPIO19, R4.1
NET "LED_RR_MOS" = R4.2, Q4.G
NET "LED_RR_OUT" = Q4.D, J6.7

# Q1-Q4.S 全部接 GND
NET "GND" = Q1.S, Q2.S, Q3.S, Q4.S, ESP32.GND

# ============ RCW LED (2个 5mm 红色 LED, 串220Ω, 直驱) ============
NET "RCW_L" = ESP32.GPIO25, R5.1
NET "RCW_L_LED" = R5.2, D1.ANODE
NET "RCW_R" = ESP32.GPIO26, R6.1
NET "RCW_R_LED" = R6.2, D2.ANODE
NET "GND_LED" = D1.CATHODE, D2.CATHODE

# ============ 蜂鸣器 (J4, 3pin) ============
# J4.1=VCC→+5V, J4.2=GND, J4.3=I/O
NET "BUZZER" = ESP32.GPIO12, J4.3

# ============ 转向开关 (J5, 4pin, 内部上拉, 短接GND触发) ============
# J5.1=左转, J5.2=右转, J5.3=双闪, J5.4=GND
NET "SW_LEFT" = ESP32.GPIO13, J5.1
NET "SW_RIGHT" = ESP32.GPIO14, J5.2
NET "SW_HAZARD" = ESP32.GPIO15, J5.3
NET "SW_GND" = J5.4

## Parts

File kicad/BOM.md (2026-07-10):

# e-Bike BSD PCB — 物料清单 (V2.7, KiCad 工程)

## PCB 规格
| 参数 | 值 |
|---|-----|
| 尺寸 | 80mm × 60mm |
| 层数 | 2 层 (双面板) |
| 板厚 | 1.6mm |
| 铜厚 | 1oz |
| 表面处理 | HASL (有铅) |

## 元件清单

### 功率模块
| 编号 | 型号 | 封装/插座 | 数量 | 立创编号 |
|---|---|---|:--:|---|
| U1 | XL7015 48V→12V | PinSocket_1x04 (4P排母) | 1 | C7467446 |
| U2 | LM2596 12V→5V | PinSocket_1x04 (4P排母) | 1 | C99388 |
| F1 | 保险丝座 + 3A 慢熔保险管 | Fuseholder 5×20mm | 1 | 5×20mm |

### MOSFET
| 编号 | 型号 | 封装 | 数量 | 立创编号 |
|---|---|---|:--:|---|
| Q1, Q2 | IRLZ44N N-MOS | TO-220 (卧装) | 2 | C259973 |

### 电阻
| 编号 | 阻值 | 封装 | 数量 | 说明 |
|---|---|---|:--:|---|
| R1, R2 | 100Ω 1/4W | Axial DIN0207 | 2 | MOSFET 栅极限流 |
| RPD1, RPD2 | 10kΩ 1/4W | Axial DIN0207 | 2 | 栅极下拉 |
| R5, R6 | 220Ω 1/4W | Axial DIN0207 | 2 | LED 限流 |

### LED
| 编号 | 类型 | 封装 | 数量 |
|---|---|---|:--:|
| D1, D2 | 5mm 红色 LED | LED_D5.0mm | 2 |

### 连接器
| 编号 | 类型 | 引脚 | 封装 | 数量 |
|---|---|:--:|---|:--:|
| J1 | 5.08mm 接线端子 | 2 | MKDS 1×2 | 1 (48V输入) |
| J2 | 5.08mm 接线端子 | 2 | MKDS 1×2 | 1 (12V输出) |
| J3 | 2.54mm 排针 | 5 | PinHeader 1×5 | 1 (雷达) |
| J4 | 2.54mm 排针 | 3 | PinHeader 1×3 | 1 (蜂鸣器) |
| J5 | 2.54mm 排针 | 4 | PinHeader 1×4 | 1 (转向开关) |
| J6 | 2.54mm 排针 | 4 | PinHeader 1×4 | 1 (C3面板) |
| J7 | 5.08mm 接线端子 | 4 | MKDS 1×4 | 1 (转向灯输出) |
| H1 | 2.54mm 排母 | 2×19 | PinSocket 2×19 | 1 (ESP32 插座) |

### ESP32
| 编号 | 型号 | 说明 |
|---|---|---|
| H1 | ESP32-DevKitC (38PIN) | 插排母, 可插拔 |

---

## 布线规则

| 网络类型 | 线宽 | 说明 |
|---|:----:|---|
| +48V 主电源 | **3.0mm** | 顶层, 到保险丝 |
| +12V 母线 | **1.5mm** | 顶层 |
| +5V 母线 | **1.0mm** | 顶层 |
| MOSFET D-S (灯路) | **1.0mm** | 顶层 |
| 信号线 (GPIO) | **0.3mm** | 顶层优先, 底层辅助 |
| GND | 铺铜 | 底层完整铜皮 + 顶层周边 |

## 布局分区

```
┌──────────────────────────────────────┐
│ [J1] [F1] [U1 XL7015]  [J2]         │ ← 高压区 (48V/12V)
│ ─────────────────────────────────── │
│        [U2 LM2596]                   │ ← 5V转换
│ ─────────────────────────────────── │
│   [J3雷达] [J4蜂鸣] [J6 C3] [J5开关]│ ← 信号外设区
│                                      │
│ ┌────────────────────┐              │
│ │ ESP32 38PIN 排母   │  [J7转向灯]  │
│ └────────────────────┘              │
│                                      │
│ [Q1] [Q2]  [D1 D2] [R..]           │ ← 功率区
└──────────────────────────────────────┘
```

## 制作步骤

1. 打开 KiCad 8.0 → `kicad/ebike-bsd.kicad_pro`
2. 打开原理图 → 检查网络连接
3. 打开 PCB → 布局 → 自动布线
4. DRC 检查 → Gerber 导出
5. 发嘉立创打样

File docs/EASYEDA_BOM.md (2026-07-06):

# EasyEDA 带封装的元件清单 (搜立创编号即可)

> 在 EasyEDA 左侧搜 **"立创商城"** 或直接输入 C 编号

## 功率模块 (淘宝买的, 用排针座)

| 编号 | 立创搜索 | 封装 | 说明 |
|---|---|---|---|
| U1 | `C7467446` | 模块, 用 4P 排针 | XL7015 48V→12V |
| U2 | `C99388` | 模块, 用 4P 排针 | LM2596 12V→5V |
| U1座 | `排针 1×4 2.54` | HDR-4P | 插模块用 |
| U2座 | `排针 1×4 2.54` | HDR-4P | 插模块用 |

## MOSFET

| 编号 | 立创搜索 | 封装 | 数量 |
|---|---|---|:--:|
| Q1-Q4 | `IRLZ44N` 或 `C259973` | **TO-220** | 4 |

## 电阻 (贴片 0805)

| 编号 | 立创搜索 | 封装 | 数量 |
|---|---|---|:--:|
| R1-R4 | `100Ω 0805 1%` | **0805** | 4 |
| R5-R6 | `220Ω 0805 1%` | **0805** | 2 |

## LED

| 编号 | 立创搜索 | 封装 | 数量 |
|---|---|---|:--:|
| D1-D2 | `LED 红色 5mm` | **LED-5MM** | 2 |

## 连接器 (全部用 2.54mm 排针/排母)

| 编号 | 立创搜索 | 封装 | 数量 |
|---|---|---|:--:|
| J3 | `排针 1×5 2.54 直插` | HDR-5P | 1（雷达） |
| J4 | `排针 1×3 2.54 直插` | HDR-3P | 1（蜂鸣器） |
| J5 | `排针 1×4 2.54 直插` | HDR-4P | 1（开关） |
| ESP32 | `排母 1×15 2.54 直插` | HDR-15P | 2（ESP32 插座） |

## 大电流端子 (5.08mm)

| 编号 | 立创搜索 | 封装 | 数量 |
|---|---|---|:--:|
| J1,J2 | `接线端子 2P 5.08 直插` | CONN-2P-5.08 | 2 |
| J6 | `接线端子 4P 5.08 直插` | CONN-4P-5.08 | 2（4路灯×2） |
| F1 | `保险丝座 5×20` | FUSE-HOLDER | 1 |

## ESP32 模块

| 编号 | 立创搜索 | 说明 |
|---|---|---|
| ESP32 | `ESP32 DevKitC` 或直接放 2×15P 排母 | 开发板插拔式 |

---

**技巧:** 搜不到带封装的元件时 → 右键元件 → **"封装管理器"** → 手动指定封装名（如 TO-220、0805、HDR-4P）。上表里的封装名都是 EasyEDA 自带的。

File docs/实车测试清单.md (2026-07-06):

# 电动自行车 BSD+转向灯 实车测试清单

**版本:** V2.4 | **日期:** 2026-07-04 | **车辆:** 48V 电瓶

---

## 🔌 启动自检

| # | 操作 | 预期 | ✔️ |
|---|---|---|:--:|
| 1 | 打开电瓶 | 蜂鸣器响 **3 声短鸣** | ⬜ |
| 2 | 等 5 秒 | 无异常蜂鸣/闪烁 | ⬜ |

---

## 🔄 转向灯（独立于雷达）

| # | 操作 | 预期 | ✔️ |
|---|---|---|:--:|
| 3 | 左转开关 | 前左+后左 LED **1.5Hz 闪烁** | ⬜ |
| 4 | 右转开关 | 前右+后右 LED **1.5Hz 闪烁** | ⬜ |
| 5 | 双闪开关 | 四灯同时 **1.5Hz 闪烁** | ⬜ |
| 6 | 关转向 | 15 秒后自动灭 | ⬜ |

---

## 📡 盲区监测 BSD（雷达）

> ⚠️ 需要后方有来车或有助手在后方 1~5m 走动

| # | 操作 | 预期 | ✔️ |
|---|---|---|:--:|
| 7 | 静止，后方无来车 | RCW LED **不亮** | ⬜ |
| 8 | 后方左侧来车/人 | **左** RCW LED 亮 | ⬜ |
| 9 | 后方右侧来车/人 | **右** RCW LED 亮 | ⬜ |
| 10 | 正后方来车（非盲区） | LED 不亮（正后 ±14° 不算盲区） | ⬜ |
| 11 | 来车离开盲区 | LED 自动灭 | ⬜ |

---

## 🔊 后碰撞预警 RCW

> ⚠️ 需要后方车**快速逼近**（>10.8 km/h，即 3 m/s）

| # | 操作 | 预期 | ✔️ |
|---|---|---|:--:|
| 12 | 后方车 <25m 快速逼近 | **蜂鸣器长鸣 + LED 亮** | ⬜ |
| 13 | 后方车保持距离或远离 | 不报警 | ⬜ |
| 14 | 后方车 >25m | 不报警 | ⬜ |

---

## 🚨 转向辅助（打转向时雷达判危）

| # | 操作 | 预期 | ✔️ |
|---|---|---|:--:|
| 15 | 打**左转** + 左后方有来车 | **蜂鸣器急促响 + 左灯快闪** | ⬜ |
| 16 | 打**左转** + 左后方无车 | 正常 1.5Hz 闪烁，无蜂鸣 | ⬜ |
| 17 | 打**右转** + 右后方有来车 | **蜂鸣器急促响 + 右灯快闪** | ⬜ |
| 18 | 打**右转** + 右后方无车 | 正常闪烁，无蜂鸣 | ⬜ |

---

## 🧹 异常/边缘场景

| # | 操作 | 预期 | ✔️ |
|---|---|---|:--:|
| 19 | 雷达被遮挡（雨天/泥巴） | LED 不亮/系统静默 | ⬜ |
| 20 | 经过路边停着的车 | LED **可能短暂亮**（低速静物，偶尔触发） | ⬜ |
| 21 | 夜间行驶 | LED 亮度适中，不刺眼 | ⬜ |
| 22 | 关机 | 一切立即停止 | ⬜ |

---

## 📊 实测数据记录

| 参数 | 实测值 |
|---|---|
| BSD 触发时目标最近距离 | ______ m |
| BSD 触发时目标角度范围 | ______ ° ~ ______ ° |
| RCW 触发时来车速度估计 | ______ km/h |
| 转向辅助误报次数 | ______ 次 |
| 系统每天用电量（估算） | ______ Ah |

---

## ⚙️ 可调参数参考

| 参数 | 当前值 | 说明 |
|---|---|---|
| RCW 速度阈值 | 3 m/s (10.8 km/h) | 低于此速度不报警 |
| RCW 距离上限 | 25 m | 超出此距离不报警 |
| 转向灯频率 | 625ms 周期 | 1.5Hz 标准 |
| 转向灯超时 | 15 秒 | 自动关闭 |
| 雷达刷新率 | 100ms (10Hz) | 目标检测频率 |

---

## 📝 备注

1. BSD 雷达**仅在检测到目标时输出数据**，无车时 LED 不亮属正常
2. 雷达不检测**远离**的目标（BSD 版本特性，产品文档确认）
3. 正后方 ±14° 范围内来车不算盲区，LED 不亮
4. 路面颠簸可能导致连接松动，建议首次骑行后检查接线

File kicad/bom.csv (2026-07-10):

Designator | Comment | Footprint | LCSC#
J1 | 48V_INPUT | 接线端子5.08-2P | C2865821
J2 | 12V_OUT | 接线端子5.08-2P | C2865821
J7 | TURN_LAMPS | 接线端子5.08-4P | C2865823
F1 | FUSE_3A | 保险丝座5x20 | C160405
U1 | XL7015_48-12V | 排母1x4+P2.54 | C7467446
U2 | LM2596_12-5V | 排母1x4+P2.54 | C99388
H1 | ESP32_DevKitC | 排母2x19+P2.54 | C2830900
Q1 | IRLZ44N | TO-220 | C259973
Q2 | IRLZ44N | TO-220 | C259973
R1 | 100Ω | 0805 | C106743
R2 | 100Ω | 0805 | C106743
RPD1 | 10kΩ | 0805 | C106750
RPD2 | 10kΩ | 0805 | C106750
R5 | 220Ω | 0805 | C106745
R6 | 220Ω | 0805 | C106745
D1 | LED_RED_5mm | LED-5MM | C106427
D2 | LED_RED_5mm | LED-5MM | C106427
J3 | RADAR | 排针1x5+P2.54 | C124373
J4 | BUZZER | 排针1x3+P2.54 | C124371
J5 | SWITCH | 排针1x4+P2.54 | C124372
J6 | C3_PANEL | 排针1x4+P2.54 | C124372

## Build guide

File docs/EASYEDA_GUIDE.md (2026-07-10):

# EasyEDA 建原理图 → PCB → 打样 完整手顺 (V2.7)

> 打开 https://lceda.cn （立创EDA，中文版，免费）→ 注册 → 新建工程

---

## 第1步：放置元件

搜以下关键词，放到图纸上：

| 编号 | 搜什么 | 数量 | 封装/说明 |
|:----:|---|:---:|---|
| J1 | `接线端子 2P 5.08` | 1 | 48V输入 |
| J2 | `接线端子 2P 5.08` | 1 | 12V输出 |
| J7 | **`接线端子 4P 5.08`** | 1 | 转向灯输出 |
| F1 | `保险丝座 5×20` | 1 | 3A慢熔 |
| U1 | `XL7015` | 1 | DC-DC 48V→12V模块 |
| U2 | `LM2596` | 1 | DC-DC 12V→5V模块 |
| **H1** | **`排母 2×19 2.54`** | **1** | ESP32 DevKitC 插座 (38pin) |
| Q1,Q2 | `IRLZ44N` | **2** | TO-220 N-MOSFET |
| R1,R2 | `100Ω` 贴片0805 | 2 | 栅极限流 |
| RPD1,RPD2 | `10kΩ` 贴片0805 | 2 | 栅极下拉 |
| R5,R6 | `220Ω` 贴片0805 | 2 | LED限流 |
| D1,D2 | `LED 5mm 红` | 2 | 指示灯 |
| J3 | `排针 1×5 2.54` | 1 | 雷达 |
| J4 | `排针 1×3 2.54` | 1 | 蜂鸣器 |
| **J5** | **`排针 1×4 2.54`** | **1** | **转向开关** |
| **J6** | **`排针 1×4 2.54`** | **1** | **C3显示面板** |

---

## 第2步：连线（完整网表）

连线从左到右、从上到下按顺序接：

### 2.1 电源部分

```
J1.1 (+)──── F1 ──── U1.1 (XL7015 IN+)
J1.2 (GND)── U1.2 (IN-) ── U1.4 (OUT-) ── 所有GND

U1.3 (OUT+ 12V) ──┬── J2.1 (12V输出+)
                    ├── U2.1 (LM2596 IN+)
                    ├── J7.3 (+12V去左灯)
                    └── J7.4 (+12V去右灯)

U2.3 (OUT+ 5V) ──┬── J3.1 (雷达VCC)
                   ├── J4.1 (蜂鸣器VCC)
                   ├── J6.4 (C3面板VCC)
                   └── ESP32 5V引脚 (排母对应脚)
```

### 2.2 转向灯驱动 (2路MOSFET)

> V2.7 每侧前+后灯在外部并联，板上只需2个MOSFET

```
ESP32 GPIO4 ──┬── R1(100Ω)── Q1.G(栅极)
               └── RPD1(10kΩ)── GND (下拉)

Q1.D(漏极) ── J7.1 (左前灯- + 左后灯- 在外部并联)
Q1.S(源极) ── GND

ESP32 GPIO23 ──┬── R2(100Ω)── Q2.G
                └── RPD2(10kΩ)── GND

Q2.D ── J7.2 (右前灯- + 右后灯- 在外部并联)
Q2.S ── GND
```

### 2.3 雷达 (J3)

| 引脚 | 信号 | 接去哪 |
|:---:|---|---|
| J3.1 | VCC | +5V |
| J3.2 | GND | GND |
| J3.3 | OUT | **悬空** |
| J3.4 | RX | **ESP32 GPIO17** |
| J3.5 | TX | **ESP32 GPIO16** |

### 2.4 蜂鸣器 (J4)

| 引脚 | 信号 | 接去哪 |
|:---:|---|---|
| J4.1 | VCC | +5V |
| J4.2 | GND | GND |
| J4.3 | I/O | **ESP32 GPIO12** |

### 2.5 C3显示面板 (J6)

| 引脚 | 信号 | 接去哪 |
|:---:|---|---|
| J6.1 | C3 TX | **ESP32 GPIO19** (U1RX) |
| J6.2 | C3 RX | **ESP32 GPIO18** (U1TX) |
| J6.3 | GND | GND |
| J6.4 | VCC | +5V |

### 2.6 转向开关 (J5)

| 引脚 | 信号 | 接去哪 |
|:---:|---|---|
| J5.1 | 左转 | **ESP32 GPIO13** (内部上拉, 闭合→GND) |
| J5.2 | 右转 | **ESP32 GPIO14** (内部上拉, 闭合→GND) |
| J5.3 | (空) | 悬空 |
| J5.4 | GND | GND |

### 2.7 RCW指示灯

```
ESP32 GPIO25 ── R5(220Ω)── D1(+)(LED红)── D1(-)── GND
ESP32 GPIO26 ── R6(220Ω)── D2(+)(LED红)── D2(-)── GND
```

### 2.8 ESP32排母对应关系 (38pin, 2×19)

ESP32 DevKitC 插座 H1，ESP32 插入后关键引脚对照：

| ESP32 GPIO | 排母引脚 | 接去哪 |
|:---:|:---:|---|
| 5V | 1 | +5V母线 |
| GND | 38 (最后一脚) | GND |
| GPIO4 | 4 | R1→Q1栅极 (左转向) |
| GPIO12 | 12 | J4.3 蜂鸣器 |
| GPIO13 | 13 | J5.1 左转开关 |
| GPIO14 | 14 | J5.2 右转开关 |
| GPIO16 | 16 | J3.5 雷达TX |
| GPIO17 | 17 | J3.4 雷达RX |
| GPIO18 | 18 | J6.2 C3 RX |
| GPIO19 | 19 | J6.1 C3 TX |
| GPIO23 | 23 | R2→Q2栅极 (右转向) |
| GPIO25 | 25 | R5→D1 左指示灯 |
| GPIO26 | 26 | R6→D2 右指示灯 |

---

## 第3步：转为PCB

1. 顶部菜单 → **设计** → **转换为PCB**
2. 自动出现新标签页，元件散落

### 布局建议 (80×60mm)

```
┌──────────────────────────────────────────┐
│ [J1] [F1] [U1 XL7015]       [J2]         │ ← 高压区(48V/12V)
│ ──────────────────────────────────────── │
│          [U2 LM2596]                     │ ← 5V区
│ ──────────────────────────────────────── │
│ [J3雷达] [J4蜂鸣] [J6 C3]   [J5开关]   │ ← 信号区
│                                          │
│ ┌────────────────────┐  [J7转向灯]      │
│ │    ESP32 排母      │                  │
│ └────────────────────┘                  │
│                                          │
│ [Q1] [Q2]    [D1 D2]  [R..]            │ ← 功率区
└──────────────────────────────────────────┘
```

### 布线规则

| 网络 | 线宽 | 说明 |
|---|:----:|---|
| +48V | **3.0mm** | 到保险丝, 粗 |
| +12V | **1.5mm** | 到灯和LM2596 |
| +5V | **1.0mm** | 到ESP32/雷达/蜂鸣器 |
| 灯输出(D-S) | **1.0mm** | MOSFET→J7 |
| 信号(GPIO) | **0.3mm** | 细线即可 |
| GND | **铺铜** | 底层完整地平面 |

3. 布线完 → **检查DRC** → 绿色=通过
4. **导出 → Gerber** → 压缩zip → 上传嘉立创下单

---

## 重点注意事项

1. **GND必须共地** — 48V/12V/5V/MOSFET S极/LED负极全部连一起，底层铺完整铜皮
2. **ESP32插反=烧** — 排母方向注意：USB口朝向板边
3. **转向灯同侧并联** — 左前(-)+左后(-)一起接J7.1；右前(-)+右后(-)一起接J7.2；灯正极全部接+12V(J7.3/J7.4)
4. **MOSFET下拉电阻** — RPD1/RPD2各10kΩ接到GND，防止ESP32未初始化时栅极悬空导致灯误亮
5. **保险丝** — 放在48V输入端，紧挨J1，用3A慢熔

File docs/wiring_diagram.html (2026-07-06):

# ◆ 单雷达 BSD 转向灯系统 — 接线图 V2.1

ESP32-32D + MS60-3015 ×1 + IRLZ44N ×4 + RCW 指示灯 + 蜂鸣器

ESP32 GPIO

电源 (48V/12V/3.3V)

MOSFET 转向灯

雷达 UART

蜂鸣器 / 指示灯

OLED (可选)

GND

## 📐 引脚分配表

ESP32 引脚 | 功能 | 连接端 | 备注
GPIO4 | PWM CH0 | Q1 栅极 → 左前转向灯 | 1kΩ 限流 + 10kΩ 下拉
GPIO5 | PWM CH1 | Q2 栅极 → 右前转向灯 | 同上
GPIO18 | PWM CH2 | Q3 栅极 → 左后转向灯 | 同上
GPIO19 | PWM CH3 | Q4 栅极 → 右后转向灯 | 同上
GPIO12 | 数字输出 | 蜂鸣器+ (1kΩ) | PWM 可调频率
GPIO13 | 输入(上拉) | 转向开关-左 → GND | 按下 = LOW
GPIO14 | 输入(上拉) | 转向开关-右 → GND | 按下 = LOW
GPIO15 | 输入(上拉) | 双闪按钮 → GND | Toggle
GPIO16 | UART2 RX | 雷达 TX | 115200bps
GPIO17 | UART2 TX | 雷达 RX | 115200bps
GPIO21 | I2C SDA | OLED SDA | 4.7kΩ 上拉 (可选)
GPIO22 | I2C SCL | OLED SCL | 4.7kΩ 上拉 (可选)
GPIO25 | 数字输出 | 左 RCW 指示灯 LED | 220Ω 限流，GPIO 直驱
GPIO26 | 数字输出 | 右 RCW 指示灯 LED | 220Ω 限流，GPIO 直驱
3.3V | 电源 | AMS1117 输出 | ESP32 + 雷达共用
GND | 电源地 | 所有 GND 共地 | 星型汇接

## 🔧 固件 V2.1

firmware/ebike_bsd.ino — 主程序 (V2.1: BSD + 转向辅助 + RCW 指示灯)
firmware/bsd_protocol.h — BSD 协议解析 + 角度分区
firmware/ms60_radar.h — 雷达 UART 驱动
firmware/led_control.h — 4路 PWM LED 驱动
firmware/oled_display.h — OLED 显示 (可选, ENABLE_OLED)

烧录: PlatformIO / Arduino IDE, Board = ESP32 Dev Module

## ⚠️ 安装注意事项

1. 雷达必须居中安装、天线面朝正后方（否则 angle 分区偏移）
2. 48V 正极务必串 5A 慢熔保险丝，紧贴电瓶端子
3. 雷达 3.3V 从 AMS1117 取电，不要用 ESP32 板载 3.3V
4. 每个 MOSFET: GPIO →1kΩ→ 栅极(G)，栅极 →10kΩ→ GND
5. 指示灯 LED: GPIO25/26 →220Ω→ LED(+) → LED(-) → GND
6. UART 线用双绞线/屏蔽线，远离 48V 电源线
7. 所有接头做防水（热缩管+硅胶密封）

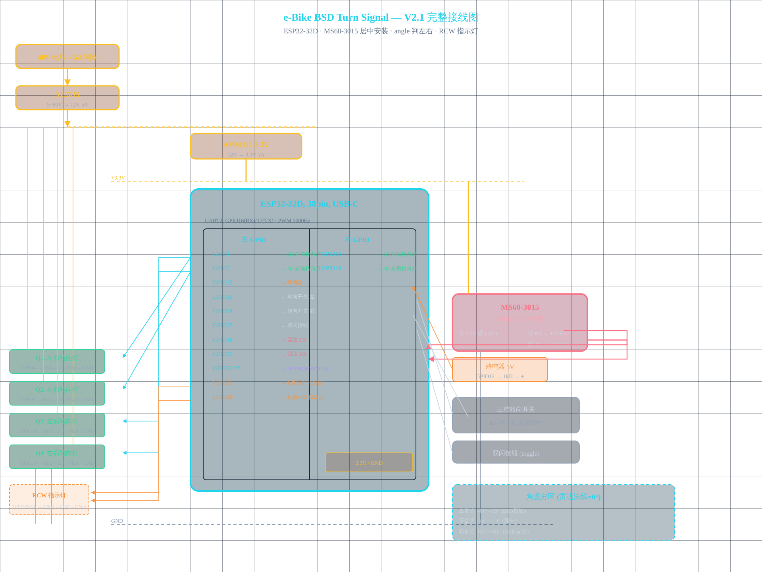
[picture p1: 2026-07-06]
docs/wiring_diagram.png

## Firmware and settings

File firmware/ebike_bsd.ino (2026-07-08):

// ============================================================
//  ebike_bsd.ino - 电动自行车进阶转向灯系统 主程序
//  硬件: ESP32 + MS60-3015 60GHz雷达 ×1 + IRLZ44N MOSFET ×4
//  版本: V2.7 — WiFi控制台 + JSON配置 + LED闪烁分级 + 目标自动消失 + StaticJsonDocument修复
// ============================================================

#include <Arduino.h>
#include "bsd_protocol.h"
#include "ms60_radar.h"
#include "led_control.h"
#include "config_store.h"
#include <esp_task_wdt.h>

#define WDT_TIMEOUT_S 5

// ============ 引脚定义 ============
#define SERIAL_DEBUG_BAUD  115200

// UART1: 雷达数据输出到C3显示面板 (GPIO18=TX, GPIO19=RX)
#define UART1_BAUD          115200
#define UART1_TX_PIN        18
#define UART1_RX_PIN        19
#define UART1_DEBUG

// UART2: 单雷达 (ESP32 UART2: GPIO16=RX, GPIO17=TX)
#define RADAR_UART_NUM     2
#define RADAR_RX_PIN       16
#define RADAR_TX_PIN       17
#define RADAR_BAUD         921600

// MOSFET 栅极 (同侧前后灯共用一个GPIO)
#define LED_LEFT_PIN       4    // 左前+左后
#define LED_RIGHT_PIN      23   // 右前+右后 (原GPIO5, 启动引脚冲突)

// 开关输入 (内部上拉, LOW=触发)
#define SW_LEFT_PIN        13   // 左转向
#define SW_RIGHT_PIN       14   // 右转向

// 蜂鸣器 (12V高分贝, IRLZ44N MOSFET驱动, HIGH=响)
#define BUZZER_PIN         12

// 指示灯 (GPIO直驱, 不需要MOSFET, 串联220Ω限流即可)
#define INDICATOR_L_PIN    25   // 左后碰撞指示灯
#define INDICATOR_R_PIN    26   // 右后碰撞指示灯

// OLED I2C (可选)
#define OLED_SDA_PIN       21
#define OLED_SCL_PIN       22

// ============ 常量 ============
#define BLINK_INTERVAL_NORMAL   667   // 1.5Hz 正常闪烁 (ms)
#define BSD_CRITICAL_SPEED     2      // m/s, >7.2km/h 视为接近
#define BSD_CRITICAL_RANGE     30     // 米, 30米内视为危险
#define MAIN_LOOP_DELAY        50     // 主循环周期 (ms)
#define BUZZER_BEEP_DURATION   150    // 蜂鸣单次时长 (ms)
#define STATE_DEBOUNCE_MS      50     // 按键消抖


// LED 指示灯模式 (独立状态机)
#define IND_MODE_OFF    0  // 灭
#define IND_MODE_BSD    1  // 1Hz 慢闪 (盲区)
#define IND_MODE_RCW    2  // 4Hz 快闪 (碰撞预警)
#define IND_MODE_TURN   3  // 常亮 (转向辅助)

// 闪烁定时: 使用 (millis()/interval) % 2 方式
// 所有 LED 都通过 updateIndicatorLEDs() 集中控制

// ============ 全局对象 ============
MS60Radar radar(RADAR_UART_NUM, RADAR_RX_PIN, RADAR_TX_PIN, RADAR_BAUD);
LEDController ledCtrl;
ConfigStore config;  // 全局配置实例

// ============ 状态变量 ============
typedef enum {
    TURN_OFF = 0,
    TURN_LEFT,
    TURN_RIGHT
} TurnState_t;

TurnState_t turn_state = TURN_OFF;
#include "wifi_web.h"

unsigned long last_blink_time = 0;
unsigned long last_bsd_beep_time = 0;
unsigned long last_buzzer_change = 0;
bool turn_led_on = false;         // 当前LED亮灭
bool bsd_l_warned = false;       // 左侧已预警
bool bsd_r_warned = false;       // 右侧已预警
bool bsd_l_active = false;       // 左盲区当前有目标
bool bsd_r_active = false;       // 右盲区当前有目标
unsigned long bsd_l_led_time = 0;  // 左LED最后触发时间
unsigned long bsd_r_led_time = 0;  // 右LED最后触发时间

// LED 模式 (由各子系统设置, updateIndicatorLEDs 集中刷新)
int ind_left_mode  = IND_MODE_OFF;   // 左指示灯当前模式
int ind_right_mode = IND_MODE_OFF;   // 右指示灯当前模式
// 闪烁用常量 (初始化默认值, 运行时从config读取)
#define BSD_IND_DEFAULT    500   // 1Hz 慢闪
#define RCW_IND_DEFAULT    125   // 4Hz 快闪

int buzzer_mode = 0;              // 0=静音, 1=短鸣(BSD), 2=4Hz(RCW), 3=长鸣(转向辅助)

// RCW 状态 (参数见config.rcw)
bool rcw_l_active = false;
bool rcw_r_active = false;
bool sim_mode = false;
bool wifi_running = true;     // WiFi状态 (被 loop 状态机和串口命令共享)
unsigned long rcw_l_time = 0;
unsigned long rcw_r_time = 0;

// ============ 函数声明 ============
void setupPins();
void updateTurnControl();
void updateTurnAssist();
void updateRCW();
void updateBuzzer();
void blinkLEDs();
void setTurnLEDs(bool on, bool left, bool right);
void updateIndicatorLEDs();
void sendRadarUART1();
void debugOutput();

// ===============================================================
//  SETUP
// ===============================================================
uint8_t hexDigit(char c) { if(c>='0'&&c<='9')return c-'0'; if(c>='A'&&c<='F')return c-'A'+10; if(c>='a'&&c<='f')return c-'a'+10; return 0; }

void setup() {
    // 禁用任务看门狗 (setup耗时较长: WiFi+雷达初始化+Flash保存)
    // 禁用任务看门狗 (setup耗时较长)
    esp_task_wdt_deinit();
    
    Serial.begin(SERIAL_DEBUG_BAUD);
    Serial1.begin(UART1_BAUD, SERIAL_8N1, UART1_RX_PIN, UART1_TX_PIN);
    Serial.println();
    Serial.println("=== e-Bike BSD Turn Signal System (V2.7) ===");
    Serial.println("Hardware: ESP32 + MS60-3015 x1 (居中安装)");

    // 加载配置 (首次开机用默认值但不写入NVS, 用户主动保存时才写)
    Serial.println("[CONFIG] 加载...");
    if (!config.loadFromNVS()) {
        Serial.println("[CONFIG] 使用默认配置 (未写入NVS)");
    }
    config.summary();

    // WiFi AP + Web控制台 (每次开机都启动, 120秒无人连自动关)
    Serial.println("[WIFI] 启动热点 (120秒无人连自动关)...");
    initWiFi();
    initWebServer();

    setupPins();

    // 初始化 LED 控制器
    ledCtrl.begin(LED_LEFT_PIN, LED_RIGHT_PIN);

    // 初始化单雷达 (UART2)
    Serial.println("[RADAR] 初始化雷达 (UART2, GPIO16/17, 921600bps)...");
    if (radar.begin()) {
        Serial.println("[RADAR] 雷达 UART OK, 等待模块启动...");
        for (int i = 0; i < 30; i++) { delay(100); yield(); }  // 3秒分段, 防看门狗
        radar.setBSDMode();
        Serial.println("[RADAR] BSD模式已设置");
    } else {
        Serial.println("[RADAR] ⚠ 雷达初始化失败, 请检查接线");
    }

    // 重新初始化看门狗 (5秒超时, 仅loopTask喂狗)
    esp_task_wdt_init(5, true);
    esp_task_wdt_add(NULL);
    
    Serial.println("=== 系统就绪 ===");
    Serial.println("[WEB] 手机连接 eBike-BSD 热点, 浏览器打开 192.168.4.1");
}

// ===============================================================
//  LOOP
// ===============================================================
void loop() {
    // ==== WiFi 自动关状态机 ====
    // 规则:
    //   - 开机: WiFi 开
    //   - 无设备连接 → 30s 后关 WiFi
    //   - 有设备连接 → 保持 WiFi 开
    //   - 设备断开 → 重新 30s 倒计时 → 关 WiFi
    static unsigned long wifi_check = 0;
    static unsigned long wifi_idle_since = 0;   // 0=有连接或未开始计时

    if (wifi_running && millis() - wifi_check > 2000) {
        wifi_check = millis();

        int sta_num = WiFi.softAPgetStationNum();

        Serial.print("[WIFI] sta=");
        Serial.print(sta_num);
        Serial.print(" idle=");
        Serial.print(wifi_idle_since ? (millis() - wifi_idle_since) / 1000 : 0);
        Serial.println("s");

        if (sta_num > 0) {
            // 有设备连接 → 重置计时
            wifi_idle_since = 0;
        } else {
            // 无设备连接
            if (wifi_idle_since == 0) {
                wifi_idle_since = millis();   // 开始空闲计时
            }

            if (millis() - wifi_idle_since >= 30000) {
                Serial.println("[WIFI] 30s无连接, 关闭WiFi");
                server.end();
                delay(50);
                WiFi.softAPdisconnect(true);
                WiFi.enableAP(false);
                WiFi.mode(WIFI_OFF);
                wifi_running = false;
            }
        }
    }

    // 1) 读取开关（含消抖）
    updateTurnControl();

    // 2) 读取雷达数据 (单雷达)
    radar.readFrame();
    radar.checkStale(500);
    
    // 2.1) 发送雷达数据到 UART1 (C3显示面板)
    sendRadarUART1();
    
    // 2.5) 自动检测雷达重连并重新配置
    static bool radar_configured = false;
    static unsigned long last_radar_rx = 0;
    if (radar.getTotalBytes() > 0) last_radar_rx = millis();
    // 雷达有数据 (>50字节 - 确保boot日志完全输出) 且尚未配置 → 发配置
    if (!radar_configured && radar.getTotalBytes() > 50) {
        radar_configured = true;
        Serial.println("[AUTO-CFG] 雷达启动完成，发送配置...");
        delay(500);  // 等雷达完全就绪
        radar.setBSDMode();
    }
    // 超时 5 秒无数据 → 重置检测 (雷达可能被热插拔了)
    if (radar_configured && (millis() - last_radar_rx) > 5000 && radar.getTotalBytes() == 0) {
        radar_configured = false;
        Serial.println("[AUTO-CFG] 雷达静默，等待重连...");
    }
    // 首次运行 5 秒后仍未检测到 → 主动发送配置
    static bool proactive_sent = false;
    if (!radar_configured && !proactive_sent && millis() > 5000) {
        proactive_sent = true;
        Serial.println("[AUTO-CFG] 超时主动配置...");
        delay(100);
        radar.setBSDMode();
        radar_configured = true;
    }

    // 2.6) 串口命令转发 (PC→ESP32→雷达)
    if (Serial.available()) {
        String line = Serial.readStringUntil('\n');
        line.trim();
        
        if (line == "BEEP") {
            digitalWrite(BUZZER_PIN, HIGH); delay(200);
            digitalWrite(BUZZER_PIN, LOW);
            Serial.println("[FWD] BEEP test");
        }
        else if (line == "SAVE") {
            config.saveToNVS();
            Serial.println("[FWD] Config saved to NVS");
        }
        else if (line == "RESET") {
            config.factoryReset();
            Serial.println("[FWD] Factory reset done, NVS cleared");
        }
        else if (line == "SIM") {
            sim_mode = !sim_mode;
            Serial.print("[FWD] SIM mode: ");
            Serial.println(sim_mode ? "ON" : "OFF");
        }
        else if (line == "WIFI") {
            Serial.println("[FWD] WiFi ON (force)");
            WiFi.mode(WIFI_AP);
            WiFi.softAP(config.sys.wifi_ssid, config.sys.wifi_pass);
            delay(100);
            server.end();
            delay(50);
            server.begin();
            wifi_running = true;
        }
        else if (line == "DUMP") {
            static StaticJsonDocument<4096> dump_doc;
            dump_doc.clear();
            config.toJson(dump_doc);
            serializeJson(dump_doc, Serial);
            Serial.println();
        }
        else if (line == "LOAD") {
            config.loadFromNVS();
            config.summary();
        }
        else if (line == "TESTPOST") {
            // 自测: ESP32给自己发POST, 验证Web服务器
            Serial.println("[TEST] Sending POST to self...");
            WiFiClient client;
            if (client.connect("192.168.4.1", 80)) {
                String body = "{\"bsd\":{\"speed\":99},\"sys\":{\"profile\":\"test\"}}";
                client.print("POST /api/config HTTP/1.1\r\n");
                client.print("Host: 192.168.4.1\r\n");
                client.print("Content-Type: application/json\r\n");
                client.print("Content-Length: " + String(body.length()) + "\r\n");
                client.print("\r\n");
                client.print(body);
                delay(500);
                while(client.available()) { client.read(); }
                client.stop();
                Serial.println("[TEST] POST sent, check serial for [WEB] response");
            } else {
                Serial.println("[TEST] FAIL: cannot connect to self");
            }
        }
        else if (line == "LOAD") {
            if (!config.loadFromNVS()) { Serial.println("[CONFIG] 写入默认配置"); config.saveToNVS(); }
            config.summary();
        }
        else if (line.startsWith("CMD:")) {
            // 解析hex: CMD:58D102005B00
            String hex = line.substring(4);
            uint8_t buf[32]; int len = 0;
            for (int i = 0; i < (int)hex.length() && len < 32; i += 2) {
                if (i+1 < (int)hex.length()) {
                    char c1 = hex[i], c2 = hex[i+1];
                    if (isxdigit(c1) && isxdigit(c2)) {
                        buf[len++] = (hexDigit(c1) << 4) | hexDigit(c2);
                    }
                }
            }
            if (len > 0) {
                Serial2.write(buf, len);
                Serial.print("[FWD] sent "); Serial.print(len); Serial.println(" bytes");
            }
        }
    }
    
    
    // 2.7) C3串口配置命令接收 (C3→ESP32)
    if (Serial1.available()) {
        String line = Serial1.readStringUntil('\n');
        line.trim();
        if (line.startsWith("$CFG,")) {
            int v[11];
            int n = sscanf(line.c_str(), "$CFG,%d,%d,%d,%d,%d,%d,%d,%d,%d,%d,%d",
                &v[0],&v[1],&v[2],&v[3],&v[4],&v[5],&v[6],&v[7],&v[8],&v[9],&v[10]);
            if (n >= 9) {
                config.rcw.low_speed       = v[0];
                config.rcw.speed_threshold = v[1];
                config.rcw.range_limit     = v[2];
                config.rcw.hold_time       = v[3];
                config.rcw.lflash_interval = v[4];
                config.rcw.flash_interval  = v[5];
                config.turn.speed_threshold= v[6];
                config.turn.range_limit    = v[7];
                config.sys.bsd_beep_cooldown = v[8];
                if (n >= 11) {
                    config.radar.det_range  = v[9];
                    config.radar.sensitivity= v[10];
                }
                config.saveToNVS();
                radar.setBSDMode();
                Serial.println("[C3] Config saved from touch panel");
            } else {
                Serial.print("[C3] Parse err: got "); Serial.print(n); Serial.println(" values");
            }
        } else if (line == "$GETCFG") {
            // 响应C3的配置请求
            static StaticJsonDocument<4096> cfg_doc;
            cfg_doc.clear();
            config.toJson(cfg_doc);
            char buf[200];
            snprintf(buf, sizeof(buf), "$CFG,%d,%d,%d,%d,%d,%d,%d,%d,%d,%d,%d",
                config.rcw.low_speed,
                config.rcw.speed_threshold,
                config.rcw.range_limit,
                config.rcw.hold_time,
                config.rcw.lflash_interval,
                config.rcw.flash_interval,
                config.turn.speed_threshold,
                config.turn.range_limit,
                config.sys.bsd_beep_cooldown,
                config.radar.det_range,
                config.radar.sensitivity);
            Serial1.print(buf); Serial1.print("\n");
            Serial.println("[C3] Config sent");
        } else if (line.startsWith("$WIFI,")) {
            int on;
            if (sscanf(line.c_str(), "$WIFI,%d", &on) == 1) {
                if (on) {
                    Serial.println("[C3] WiFi ON");
                    WiFi.mode(WIFI_AP);
                    WiFi.softAP(config.sys.wifi_ssid, config.sys.wifi_pass);
                    server.begin();
                } else {
                    Serial.println("[C3] WiFi OFF");
                    server.end();
                    delay(50);
                    WiFi.softAPdisconnect(true);
                    WiFi.enableAP(false);
                    WiFi.mode(WIFI_OFF);
                }
            }
        }
    }
    
    // 3) 后方监测 (BSD+RCW合并): 低速→慢闪, 高速→快闪
    ind_left_mode = IND_MODE_OFF;
    ind_right_mode = IND_MODE_OFF;
    updateRCW();

    // 4) 转向辅助 (打转向灯时判断该方向是否有危险)
    if (turn_state == TURN_LEFT || turn_state == TURN_RIGHT) {
        updateTurnAssist();
    }

    // 6) LED 闪烁控制 (转向灯/双闪 PWM)
    blinkLEDs();

    // 6.5) 指示灯状态机 (BSD/RCW/转向辅集中刷新)
    updateIndicatorLEDs();

    // 7) 蜂鸣器状态机
    updateBuzzer();

    // 8) 调试输出 (每2秒, WiFi模式下降低频率避免串口争用)
    static unsigned long last_debug = 0;
    if (millis() - last_debug > 2000) {
        last_debug = millis();
        debugOutput();
    }

    esp_task_wdt_reset();    // 喂看门狗

    delay(MAIN_LOOP_DELAY);
    yield();                 // 让出CPU给WiFi/Web回调
}

// ===============================================================
//  引脚初始化
// ===============================================================
void setupPins() {
    // MOSFET 栅极 (初始LOW=关闭)
    pinMode(LED_LEFT_PIN, OUTPUT);
    pinMode(LED_RIGHT_PIN, OUTPUT);
    digitalWrite(LED_LEFT_PIN, LOW);
    digitalWrite(LED_RIGHT_PIN, LOW);

    // 开关 (内部上拉)
    pinMode(SW_LEFT_PIN, INPUT_PULLUP);
    pinMode(SW_RIGHT_PIN, INPUT_PULLUP);

    // 蜂鸣器
    pinMode(BUZZER_PIN, OUTPUT);
    digitalWrite(BUZZER_PIN, LOW);
    
    // === 蜂鸣器自检 (短鸣 3 声) ===
    Serial.println("[TEST] 蜂鸣器自检...");
    for(int i=0;i<3;i++){
        digitalWrite(BUZZER_PIN, HIGH); delay(100);
        digitalWrite(BUZZER_PIN, LOW);  delay(100);
    }

    // 指示灯 (GPIO直驱LED, 串联220Ω, 初始灭)
    pinMode(INDICATOR_L_PIN, OUTPUT);
    pinMode(INDICATOR_R_PIN, OUTPUT);
    digitalWrite(INDICATOR_L_PIN, LOW);
    digitalWrite(INDICATOR_R_PIN, LOW);
}

// ===============================================================
//  转向控制 — 自锁式三档开关 (LEFT=LOW / RIGHT=LOW / 中间=OFF)
// ===============================================================
void updateTurnControl() {
    bool sw_l = digitalRead(SW_LEFT_PIN);
    bool sw_r = digitalRead(SW_RIGHT_PIN);

    // 三档开关 (自锁式, 直接读电平)
    if (sw_l == LOW && turn_state != TURN_LEFT) {
        turn_state = TURN_LEFT;
        Serial.println("[SW] 左转向 ON");
    } else if (sw_r == LOW && turn_state != TURN_RIGHT) {
        turn_state = TURN_RIGHT;
        Serial.println("[SW] 右转向 ON");
    } else if (sw_l == HIGH && sw_r == HIGH && turn_state != TURN_OFF) {
        turn_state = TURN_OFF;
        Serial.println("[SW] 转向 OFF");
    }
}

// ===============================================================
//  盲区监测 (BSD) — 单雷达, angle判左右
// ===============================================================


// ===============================================================
//  转向辅助: 打灯时判断同侧危险
//  从同一个雷达数据中, 按 angle 筛选同侧目标
// ===============================================================
void updateTurnAssist() {
    BSDFrame *f = radar.getFrame();
    if (!f->valid) return;   // 帧无效则跳过

    // 帧新鲜度检查: 只用新帧, 避免旧帧重复触发
    static uint32_t last_ts_turn = 0;
    if (f->timestamp == last_ts_turn) return;
    last_ts_turn = f->timestamp;

    bool danger = false;

    for (int i = 0; i < f->obj_num && i < 8; i++) {
        BSDObj *obj = &f->objects[i];
        if (obj->range <= 0 || obj->range >= config.turn.range_limit) continue;
        if (obj->velocity < config.turn.speed_threshold) continue;

        if (turn_state == TURN_LEFT) {
            // 左转: 角度在左后方 -40°~-5° 且有接近速度
            if (TURN_ANGLE_IS_LEFT(obj->angle)) {
                danger = true;
                break;
            }
        } else if (turn_state == TURN_RIGHT) {
            // 右转: 角度在右后方 +5°~+40°
            if (TURN_ANGLE_IS_RIGHT(obj->angle)) {
                danger = true;
                break;
            }
        }
    }

    if (danger) {
        // 驱动同侧指示灯 (GPIO直驱LED) 作为视觉警示
        if (turn_state == TURN_LEFT) {
            ind_left_mode = IND_MODE_TURN;
        } else {
            ind_right_mode = IND_MODE_TURN;
        }
        buzzer_mode = 3;  // 转向辅助: 持续长鸣
        Serial.println("[ASSIST] ⚠ 转向侧有接近车辆！");
    } else {
        // 仅清除本侧指示灯, 不覆盖 RCW 已设的
        if (turn_state == TURN_LEFT && !rcw_l_active) {
            // LED mode cleared by ind_left_mode reset at top of loop
        } else if (turn_state == TURN_RIGHT && !rcw_r_active) {
            // LED mode cleared by ind_right_mode reset at top of loop
        }
        if ((buzzer_mode == 2 || buzzer_mode == 3) && !rcw_l_active && !rcw_r_active) {
            buzzer_mode = 0;
        }
    }
}

// ===============================================================
//  后碰撞预警 (RCW)
//  无转向灯时, 检测后方快速接近 → 亮对应指示灯
//  指示灯(5mm LED, GPIO直驱) 常亮, 蜂鸣器4Hz响
//  与转向灯完全独立, 互不干扰
// ===============================================================
// ===============================================================
//  后方监测 (BSD+RCW合并): 按速度两级报警
//    低速 (≥low_speed): IND_MODE_BSD (1Hz慢闪) + 蜂鸣单声
//    高速 (≥speed_threshold): IND_MODE_RCW (4Hz快闪) + 蜂鸣4Hz
// ===============================================================
void updateRCW() {
    BSDFrame *f = radar.getFrame();
    if (!f->valid) {
        buzzer_mode = 0;
        return;
    }
    unsigned long now = millis();
    
    // 新帧→更新检测状态
    static uint32_t last_ts = 0;
    static unsigned long last_low_beep_l = 0;
    static unsigned long last_low_beep_r = 0;
    if (f->timestamp != last_ts) {
        last_ts = f->timestamp;
        
        bool leftLow=false, rightLow=false, leftHigh=false, rightHigh=false;
        for (int i = 0; i < f->obj_num && i < 8; i++) {
            BSDObj *obj = &f->objects[i];
            if (obj->range <= 0 || obj->range > config.rcw.range_limit) continue;
            
            // 速度分级
            bool isHigh = (obj->velocity >= config.rcw.speed_threshold);
            bool isLow  = (obj->velocity >= config.rcw.low_speed && !isHigh);
            
            if (REAR_ANGLE_IS_LEFT(obj->angle)) {
                if (isHigh) leftHigh = true;
                else if (isLow) leftLow = true;
            }
            if (REAR_ANGLE_IS_RIGHT(obj->angle)) {
                if (isHigh) rightHigh = true;
                else if (isLow) rightLow = true;
            }
        }
        
        // 左侧: 高优先 → 低优先
        if (leftHigh) {
            if (!rcw_l_active) Serial.println("[RCW] ⚡ 左后方有车辆快速接近!");
            rcw_l_active = true; rcw_l_time = now;
            ind_left_mode = IND_MODE_RCW; buzzer_mode = 2;
        } else if (leftLow) {
            if (!rcw_l_active) Serial.println("[RCW] 🔹 左侧盲区有车辆");
            rcw_l_active = true; rcw_l_time = now;
            ind_left_mode = IND_MODE_BSD;
            // 低速蜂鸣有5秒冷却
            if (now - last_low_beep_l > (unsigned long)config.sys.bsd_beep_cooldown) {
                buzzer_mode = 1; last_low_beep_l = now;
            }
        }
        // 右侧: 高优先 → 低优先
        if (rightHigh) {
            if (!rcw_r_active) Serial.println("[RCW] ⚡ 右后方有车辆快速接近!");
            rcw_r_active = true; rcw_r_time = now;
            ind_right_mode = IND_MODE_RCW; buzzer_mode = 2;
        } else if (rightLow) {
            if (!rcw_r_active) Serial.println("[RCW] 🔹 右侧盲区有车辆");
            rcw_r_active = true; rcw_r_time = now;
            ind_right_mode = IND_MODE_BSD;
            if (now - last_low_beep_r > (unsigned long)config.sys.bsd_beep_cooldown) {
                buzzer_mode = 1; last_low_beep_r = now;
            }
        }
    }
    
    // 超时解除
    if (rcw_l_active && (now - rcw_l_time > (unsigned long)config.rcw.hold_time)) {
        rcw_l_active = false;
    }
    if (rcw_r_active && (now - rcw_r_time > (unsigned long)config.rcw.hold_time)) {
        rcw_r_active = false;
    }
    if (!rcw_l_active && !rcw_r_active) buzzer_mode = 0;
}
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

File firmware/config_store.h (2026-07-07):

// ============================================================
//  config_store.h - 配置存储 (JSON + NVS)
//  V2.5+: 所有 #define 参数迁移到结构体, JSON序列化到NVS
// ============================================================
#ifndef CONFIG_STORE_H
#define CONFIG_STORE_H

#include <Arduino.h>
#include <Preferences.h>
#include <ArduinoJson.h>

// ============ 配置结构体 ============

struct RCWParams {
    int left_angle_min  = -40;     // °, 左检测区起始
    int left_angle_max  = -5;      // °, 左检测区结束
    int right_angle_min = 5;       // °, 右检测区起始
    int right_angle_max = 40;      // °, 右检测区结束
    int low_speed       = 2;       // m/s, 低警告阈值
    int speed_threshold = 3;       // m/s, 高警告阈值
    int range_limit     = 25;      // m
    int hold_time       = 3000;    // ms
    int flash_interval  = 125;     // ms, 高LED半周期 (4Hz)
    int lflash_interval = 500;     // ms, 低LED半周期 (1Hz)
};

struct TurnAssistParams {
    int left_angle_min  = -40;
    int left_angle_max  = -5;
    int right_angle_min = 5;
    int right_angle_max = 40;
    int speed_threshold = 2;       // m/s
    int range_limit     = 30;      // m
};

struct SystemParams {
    char wifi_ssid[32]     = "eBike-BSD";
    char wifi_pass[32]     = "12345678";
    int  led_brightness    = 255;
    int  bsd_beep_cooldown = 5000;
};

struct RadarParams {
    int baud_rate     = 921600;  // UART波特率
    int det_range     = 30;      // 最大探测距离 (m)
    int sensitivity   = 2;       // 灵敏度 (0-10, 越小越灵敏)
};

// ============ 全局配置类 ============
class ConfigStore {
public:
    RCWParams       rcw;
    TurnAssistParams turn;
    SystemParams     sys;
    RadarParams      radar;

    // ---- JSON 序列化 ----
    void toJson(JsonDocument &doc) {
        JsonObject r = doc["rcw"].to<JsonObject>();
        r["left_min"]  = rcw.left_angle_min;
        r["left_max"]  = rcw.left_angle_max;
        r["right_min"] = rcw.right_angle_min;
        r["right_max"] = rcw.right_angle_max;
        r["low_speed"] = rcw.low_speed;
        r["speed"]     = rcw.speed_threshold;
        r["range"]     = rcw.range_limit;
        r["hold"]      = rcw.hold_time;
        r["lflash"]    = rcw.lflash_interval;
        r["flash"]     = rcw.flash_interval;

        JsonObject t = doc["turn"].to<JsonObject>();
        t["left_min"]  = turn.left_angle_min;
        t["left_max"]  = turn.left_angle_max;
        t["right_min"] = turn.right_angle_min;
        t["right_max"] = turn.right_angle_max;
        t["speed"]     = turn.speed_threshold;
        t["range"]     = turn.range_limit;

        JsonObject s = doc["sys"].to<JsonObject>();
        s["wifi_ssid"] = sys.wifi_ssid;
        s["bsd_beep_cooldown"] = sys.bsd_beep_cooldown;
        s["led_brightness"] = sys.led_brightness;

        JsonObject rd = doc["radar"].to<JsonObject>();
        rd["det_range"]   = radar.det_range;
        rd["sensitivity"] = radar.sensitivity;
    }

    void fromJson(JsonDocument &doc) {
        JsonObject r = doc["rcw"];
        if (r) {
            rcw.left_angle_min  = r["left_min"]  | rcw.left_angle_min;
            rcw.left_angle_max  = r["left_max"]  | rcw.left_angle_max;
            rcw.right_angle_min = r["right_min"] | rcw.right_angle_min;
            rcw.right_angle_max = r["right_max"] | rcw.right_angle_max;
            rcw.low_speed       = r["low_speed"] | rcw.low_speed;
            rcw.speed_threshold = r["speed"] | rcw.speed_threshold;
            rcw.range_limit     = r["range"] | rcw.range_limit;
            rcw.hold_time       = r["hold"]  | rcw.hold_time;
            rcw.lflash_interval = r["lflash"] | rcw.lflash_interval;
            rcw.flash_interval  = r["flash"] | rcw.flash_interval;
        }
        JsonObject t = doc["turn"];
        if (t) {
            turn.left_angle_min  = t["left_min"]  | turn.left_angle_min;
            turn.left_angle_max  = t["left_max"]  | turn.left_angle_max;
            turn.right_angle_min = t["right_min"] | turn.right_angle_min;
            turn.right_angle_max = t["right_max"] | turn.right_angle_max;
            turn.speed_threshold = t["speed"]     | turn.speed_threshold;
            turn.range_limit     = t["range"]     | turn.range_limit;
        }
        JsonObject s = doc["sys"];
        if (s) {
            if (s["wifi_ssid"]) strlcpy(sys.wifi_ssid, s["wifi_ssid"], sizeof(sys.wifi_ssid));
            sys.bsd_beep_cooldown = s["bsd_beep_cooldown"] | sys.bsd_beep_cooldown;
        }
        JsonObject rd = doc["radar"];
        if (rd) {
            radar.det_range   = rd["det_range"]   | radar.det_range;
            radar.sensitivity = rd["sensitivity"] | radar.sensitivity;
        }

    }
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

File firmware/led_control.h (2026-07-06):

// ============================================================
//  led_control.h - LED PWM 控制 (ESP32 Arduino Core 3.x 兼容)
//  封装4路MOSFET驱动的GPIO输出
// ============================================================
#ifndef LED_CONTROL_H
#define LED_CONTROL_H

#include <Arduino.h>

#define PWM_FREQ     5000    // 5kHz, 足以驱动LED无闪烁
#define PWM_RES      8       // 8bit 分辨率 (0-255)
#define PWM_DUTY_ON  255     // 100% 亮度
#define PWM_DUTY_OFF 0

class LEDController {
private:
    uint8_t _pins[4];
    bool    _initialized[4];
    int     _count;

public:
    LEDController() : _count(0) {
        for (int i = 0; i < 4; i++) {
            _pins[i] = 0;
            _initialized[i] = false;
        }
    }

    // 初始化4个LED通道 (ESP32 Core 3.x: ledcAttach 自动分配通道)
    void begin(uint8_t pin_l, uint8_t pin_r, uint8_t = 0, uint8_t = 0) {
        addChannel(pin_l);
        addChannel(pin_r);
        allOff();
    }

    void addChannel(uint8_t gpio) {
        if (_count >= 4) return;
        pinMode(gpio, OUTPUT);
        digitalWrite(gpio, LOW);
        _pins[_count] = gpio;
        _initialized[_count] = true;
        _count++;
    }

    // 设置某个GPIO的LED
    void set(uint8_t gpio, bool on) {
        pinMode(gpio, OUTPUT);  // 确保引脚模式
        digitalWrite(gpio, on ? HIGH : LOW);
    }

    // PWM调光 (0-255)
    void setBrightness(uint8_t gpio, uint8_t duty) {
        for (int i = 0; i < _count; i++) {
            if (_pins[i] == gpio) {
                ledcWrite(gpio, duty);
                return;
            }
        }
    }

    void allOff() {
        for (int i = 0; i < _count; i++) {
            if (_initialized[i]) digitalWrite(_pins[i], LOW);
        }
    }

    void allOn() {
        for (int i = 0; i < _count; i++) {
            if (_initialized[i]) digitalWrite(_pins[i], HIGH);
        }
    }

    int count() { return _count; }
};

#endif // LED_CONTROL_H

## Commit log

2026-07-06 V2.7: WiFi状态机修复 + 目标自动消失 + StaticJsonDocument栈溢出修复
    - WiFi 自动关重写为二态状态机(有连接清零/无连接累计30s关)
    - 新增 checkStale(500ms) 解决目标消失后红点残留
    - StaticJsonDocument 改用 static 修饰(BSS段分配,防栈溢出)
    - ArduinoJson 6.x API 适配(createNestedObject)
    - platformio.ini 新增库依赖
    - 版本号同步 V2.7
    [ebike-bsd.kicad_pcb, ebike-bsd.kicad_sch]
2026-07-06 V2.7: BSD彻底删除 + NVS清理 + 保存错误检查 + 串口命令
    - 删除 BSDParams 结构体(7字段), BSD已与RCW合并
    - ANGLE_IS_* 内联函数改读 config.rcw
    - toJson/fromJson 移除 BSD 分支, JSON从448B→346B
    - factoryReset 补上 sys 参数组重置
    - saveToNVS 增加 putString 返回值检查 + 串口调试日志
    - POST handler 检查 saveToNVS 返回值
    - 新增 RESET(出厂重置) 和 DUMP(打印完整JSON) 串口命令
    - NVS 分区擦除清理 V2.5 历史残留数据
    - 文档同步: 21参数审计, BSD废弃说明
    [config_store.h, ebike_bsd.ino]
2026-07-07 Fix KiCad文件格式: 版本号20240108, 移除(str)包装, 兼容KiCad 8
    [ebike-bsd.kicad_pcb, ebike-bsd.kicad_sch]
2026-07-07 V2.7: 修复NVS持久化 - 启动失败不再覆盖用户配置
    - loadFromNVS 失败时仅用内存默认值，不写入 NVS
    - loadFromNVS 增加详细调试日志 (NVS open/key empty/raw JSON)
    - 防止每次启动失败时默认值覆盖用户保存的自定义参数
    [config_store.h, ebike_bsd.ino]
2026-07-08 V2.7 文档更新: C3触摸显示面板 + 完整参数配置说明
2026-07-08 V2.7-C3: C3触摸显示面板 + WiFi远程控制 + 配置刷新
    ESP32:
    - WiFi远程开关 (串口WIFI命令 + C3 协议)
    - C3配置请求响应 ()
    - wifi_running改为全局变量, 状态机同步
    - 修复WiFi重启 (server.end→delay→server.begin)
    C3 (c3-display/):
    - v2.9 触摸雷达显示器
    - 全屏120°扇形图, 4条距离弧线
    - 4页触摸配置 (RCW1/RCW2/TURN/SYS)
    - REFRESH 按钮从ESP32同步参数
    - WiFi ON/OFF 开关
    - 硬件SPI + FT6336触摸
    [ebike_bsd.ino, test_uart.ino]
2026-07-08 V2.7-C3: 新增C3连接状态指示 — 左上角绿点ON/红点LOST基于ESP32心跳超时1.5s判定
2026-07-09 V2.7-C3: platformio.ini添加src_dir和lib_deps(ArduinoJson,AsyncTCP,ESPAsyncWebServer)
2026-07-10 V2.7: PCB设计文件更新 — 原理图/PCB/BOM/EasyEDA手顺 同步V2.7引脚(2-MOSFET+C3面板)
    [ebike-bsd.kicad_sch]
2026-07-10 fix: KiCad原理图括号不匹配
    [ebike-bsd.kicad_sch]
2026-07-10 fix: KiCad 10.0格式兼容 — 扁平坐标(at x y)+UUID+全局标签
    [ebike-bsd.kicad_sch]
2026-07-10 V2.7: KiCad网表文件(net) + 原理图手工绘制说明
2026-07-10 fix: 封装名兼容KiCad 10.0 — TerminalBlock_Phoenix + PinSocket
    [ebike-bsd.kicad_sch]
2026-07-10 V2.7: 改用EasyEDA(立创EDA) — 完整手顺+BOM CSV
    [bom.csv]
